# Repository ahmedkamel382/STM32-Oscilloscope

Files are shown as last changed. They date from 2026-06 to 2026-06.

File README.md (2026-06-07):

# ⚡ Digital Storage Oscilloscope (STM32F401)






A high-performance, low-cost Digital Storage Oscilloscope (DSO) engineered from the component level up. Built around the **STM32F401 "Black Pill"**, this project bridges embedded hardware and modern data science by combining a custom Analog Front-End (AFE), deterministic DMA-paced sampling, high-speed USB-CDC telemetry, and an offline Machine Learning waveform classifier.

This project was developed for the **Embedded Systems (ECE5206)** course at the **Arab Academy for Science, Technology and Maritime Transport (AASTMT)**, supervised by **Dr. Amr Fahmy**.

---

## 🚀 Key Features

* **Bipolar Signal Acquisition:** A custom analog conditioning circuit featuring a 1.65V virtual ground allows the single-supply microcontroller ADC to safely read alternating current (AC) waveforms.
* **Active Hardware Protection:** Bipolar Junction Transistor (BJT) clamping arrays (`2N3904` / `2N3906`) actively protect the STM32 silicon from over-voltage and negative voltage spikes.
* **Deterministic Firmware Architecture:** Hardware Timer 2 (`TIM2`) strictly paces ADC conversions, completely bypassing software polling delays.
* **Zero-Loss Data Capture:** Direct Memory Access (DMA) utilizing a Ping-Pong (Half/Full) buffering strategy ensures continuous, uninterrupted sampling while the CPU processes data.
* **High-Speed USB Streaming:** A custom USB-CDC pipeline streams raw binary data (736-byte packets) to the host PC, vastly outperforming standard UART communication.
* **Edge AI Classification:** A fully offline `scikit-learn` Random Forest machine learning model analyzes live mathematical features to automatically classify incoming signals (`Sine`, `Square`, `Triangle`, `Noise`, or `DC`).
* **Zero-Lag Desktop UI:** A multi-threaded Python companion application built with `PyQtGraph` delivers 60-FPS real-time rendering alongside an embedded SQLite database for waveform logging.

---

## 🧰 Technology Stack

### Hardware

* **Microcontroller:** STM32F401CCU6 (`84 MHz Core`, `48 MHz USB`)
* **Local Display:** 240×240 ST7789 TFT Display (`SPI`)
* **Analog Front-End:** Precision `33kΩ / 10kΩ` attenuation networks with `2N3904/06` hardware clamps
* **PCB Design:** Custom single-sided PCB routed in KiCad with dedicated power-rail decoupling

### Software & Firmware

* **Embedded Development:** C/C++, STM32CubeIDE (`HAL` & `LL Drivers`)
* **Desktop Application:** Python 3, PyQtGraph, PyQt5, SQLite3
* **Machine Learning:** `scikit-learn`, `numpy`, `joblib`

> The AI classifier was trained on approximately **6,000 synthesized waveforms**.

---

## 📊 Hardware Specifications & Limits

| Specification | Value | Notes |
|---|---|---|
| **Max Input Voltage** | ~ `-5.44V` to `+8.74V` | Scaled via a `0.1315` attenuation factor |
| **Max Sampling Rate** | ~ `1.56 Msps` | ADCCLK pushed to `42 MHz (DIV2)` |
| **Practical Bandwidth** | ~ `150 kHz` | Based on requiring 10 data points per wave cycle |
| **Hardware Filter** | RC Low-Pass | V1.0 uses a `33pF` capacitor (`102 MHz` cutoff). V2.0 recommends a `4.7nF` capacitor to align the anti-alias cutoff to approximately `720 kHz`. |

---

## ⚙️ Getting Started

### 1. Hardware Setup

1. Assemble the Analog Front-End using the provided KiCad schematics located in:

```text
/Hardware Design
```

2. Ensure proper grounding between the device under test (for example, an ICL8038 signal generator) and the STM32.

3. Connect the STM32 board to your PC using a USB Type-C cable.

---

### 2. Firmware Flashing

1. Open the project using **STM32CubeIDE**.
2. Build the firmware.
3. Flash the firmware to the STM32F401 using an **ST-Link V2** programmer.

---

### 3. Running the Desktop Application

Ensure Python 3 is installed on your system.

Navigate to the desktop application directory and install the dependencies:

```bash
cd dso_pc
pip install -r requirements.txt
```

Launch the desktop UI:

```bash
python dso_app.py
```

> The AI classifier (`dso_model.joblib`) is pre-trained.
>
> If you wish to retrain the model using different parameters, execute:
>
> ```bash
> python train_model.py
> ```
>
> before launching the application.

---

## 👨‍💻 Project Team

### Ahmed Khalid Mohamed

* Lead Analog HW & USB Architect
* 1.65V Virtual Ground & Attenuation Mathematics
* High-Speed USB-CDC Binary Pipeline
* Python Packet Decoding (`dso_protocol.py`)

### Adel Alaa

* Lead Display Driver & AI Engineer
* ST7789 High-Speed Column-Redraw Renderer
* KiCad PCB Routing & Hardware Decoupling
* Live Machine Learning UI Integration

### Bassel Adel

* Lead ADC Firmware & PC UI Engineer
* TIM2-Paced Hardware ADC Triggering
* DMA Ping-Pong Buffering Architecture
* Multithreaded PyQtGraph Desktop UI

### Omar Abdel Nasser Omar

* Lead DSP Firmware & Database Engineer
* Peak-Hold & Interpolation DSP Algorithms
* SQLite Waveform Database Logging
* Random Forest AI Model Training

---

## 📝 License & Academic Disclaimer

This repository contains academic coursework and is provided **as-is** for educational purposes. Do **not** connect this device directly to mains AC voltage or high-voltage circuits without proper industrial isolation and safety equipment.

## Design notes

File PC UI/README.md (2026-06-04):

# AAST DSO — Laptop Companion App

A desktop oscilloscope viewer for the STM32F401 DSO. It reads the device's
existing USB-CDC stream (**no firmware change needed**) and adds a big zoomable
display, cursors, a readings database, and a **real offline AI classifier**.

## Features
- **Live waveform** on a fast PyQtGraph plot. Mouse-drag to pan, scroll to zoom;
  *View → Autoscale* fits the trace.
- **Cursors** (tick the "Cursors" box): two time + two voltage lines; the status
  bar shows Δt and ΔV.
- **0 V offset line** — draggable dashed reference line.
- **Measurements panel** — Vpp / Vmax / Vmin / Vavg / Vrms / Freq / Period,
  straight from the device (so they match the ST7789).
- **Calibration switch** — Config C (current firmware) or Config A (after the
  fix), so the plotted voltage matches the screen.
- **Readings database (SQLite)** — Save a frame, then Overlay one on the live
  trace, Compare two side-by-side, Delete, or Export the list to CSV.
- **AI classifier** — a genuine scikit-learn RandomForest trained offline on
  synthesised sine/square/triangle/noise/DC frames. No internet required.

## Install
```
pip install -r requirements.txt
```

## Run
1. Connect the Black Pill's **own USB-C cable** to the laptop (not the ST-Link).
2. `python dso_app.py`
3. Pick the serial port (press ↻ to rescan) and click **Connect**.

The model `dso_model.joblib` ships ready-trained. To retrain it yourself:
```
python train_model.py
```

## Files
- `dso_app.py` — the GUI application
- `dso_protocol.py` — parses the 736-byte USB packet (96-byte header + 320 samples)
- `dso_features.py` — shared feature extractor (used by app **and** trainer)
- `train_model.py` — synthesises data and trains `dso_model.joblib`
- `dso_model.joblib` — the trained classifier
- `dso_readings.db` — created on first save

## Notes
- If `dso_model.joblib` or scikit-learn is missing, the classifier falls back to
  a crest-factor heuristic so the app still runs.
- A flat trace (<~10 mV motion) is reported as **DC** directly.
- The classifier reaches 100% on sine/square/triangle and ~80% on noise vs DC
  (they overlap at low amplitude) on held-out synthetic data — report it honestly.

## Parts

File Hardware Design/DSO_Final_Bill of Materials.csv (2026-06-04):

Reference | Qty | Value | DNP | Exclude from BOM | Exclude from Board | Footprint | Datasheet
C1 | 1 | 33pF |  |  |  | Capacitor_THT:C_Disc_D5.0mm_W2.5mm_P5.00mm
C2,C5 | 2 | 10uF |  |  |  | Capacitor_THT:CP_Radial_D5.0mm_P2.50mm
C3,C4 | 2 | 100nF |  |  |  | Capacitor_THT:C_Disc_D5.0mm_W2.5mm_P5.00mm
J1 | 1 | Conn_Coaxial |  |  |  | Connector_Coaxial:BNC_TEConnectivity_1478035_Horizontal
J2 | 1 | Conn_01x08 |  |  |  | Connector_PinHeader_2.54mm:PinHeader_1x08_P2.54mm_Vertical
J4,J5 | 2 | Conn_01x20 |  |  |  | Connector_PinHeader_2.54mm:PinHeader_1x20_P2.54mm_Vertical
Q1 | 1 | 2N3906 |  |  |  | Package_TO_SOT_THT:TO-92_Inline_Wide | https://www.onsemi.com/pub/Collateral/2N3906-D.PDF
Q2 | 1 | 2N3904 |  |  |  | Package_TO_SOT_THT:TO-92_Inline_Wide | https://www.onsemi.com/pub/Collateral/2N3903-D.PDF
R1 | 1 | 33k |  |  |  | Resistor_THT:R_Axial_DIN0207_L6.3mm_D2.5mm_P10.16mm_Horizontal
R2,R4,R5 | 3 | 10k |  |  |  | Resistor_THT:R_Axial_DIN0207_L6.3mm_D2.5mm_P10.16mm_Horizontal
R3 | 1 | 47R |  |  |  | Resistor_THT:R_Axial_DIN0207_L6.3mm_D2.5mm_P10.16mm_Horizontal
SW1,SW2,SW3,SW4 | 4 | SW_Push |  |  |  | Button_Switch_THT:SW_PUSH_6mm

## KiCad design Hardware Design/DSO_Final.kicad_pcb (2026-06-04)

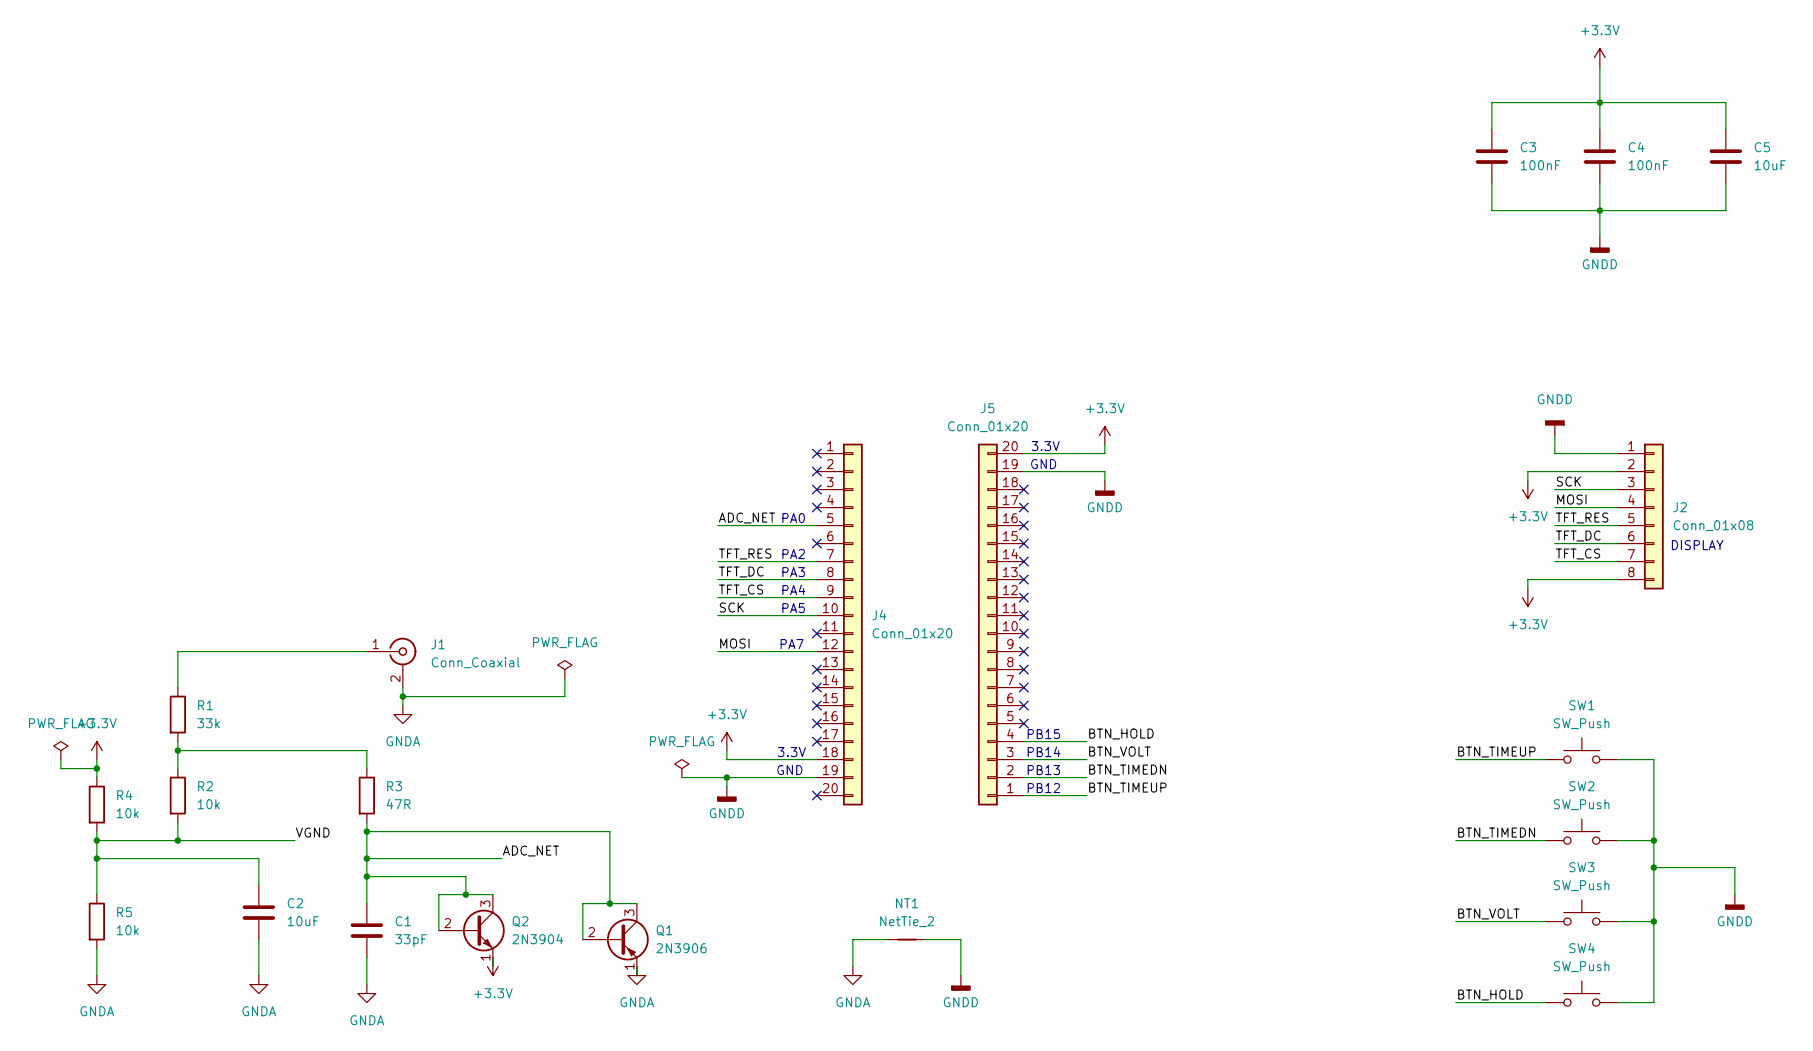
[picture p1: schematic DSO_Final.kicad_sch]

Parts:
C1: 33pF; C_Disc_D5.0mm_W2.5mm_P5.00mm
C2, C5: 10uF; CP_Radial_D5.0mm_P2.50mm
C3, C4: 100nF; C_Disc_D5.0mm_W2.5mm_P5.00mm
J1: Conn_Coaxial; BNC_TEConnectivity_1478035_Horizontal
J2: Conn_01x08; PinHeader_1x08_P2.54mm_Vertical
J4, J5: Conn_01x20; PinHeader_1x20_P2.54mm_Vertical
NT1: NetTie_2; NetTie-2_SMD_Pad0.5mm
Q1: 2N3906; TO-92_Inline_Wide
Q2: 2N3904; TO-92_Inline_Wide
R1: 33k; R_Axial_DIN0207_L6.3mm_D2.5mm_P10.16mm_Horizontal
R2, R4, R5: 10k; R_Axial_DIN0207_L6.3mm_D2.5mm_P10.16mm_Horizontal
R3: 47R; R_Axial_DIN0207_L6.3mm_D2.5mm_P10.16mm_Horizontal
SW1, SW2, SW3, SW4: SW_Push; SW_PUSH_6mm

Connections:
+3.3V: C3.1, C4.1, C5.1, J2.2, J2.8, J4.18, J5.20, Q2.1 (E), R4.1
/ADC_NET: C1.1, J4.5, Q1.2 (B), Q1.3 (C), Q2.2 (B), Q2.3 (C), R3.2
/BTN_HOLD: J5.4, SW4.1
/BTN_TIMEDN: J5.2, SW2.1
/BTN_TIMEUP: J5.1, SW1.1
/BTN_VOLT: J5.3, SW3.1
/MOSI: J2.4, J4.12
/SCK: J2.3, J4.10
/TFT_CS: J2.7, J4.9
/TFT_DC: J2.6, J4.8
/TFT_RES: J2.5, J4.7
/VGND: C2.1, R2.2, R4.2, R5.1
GNDA: C1.2, C2.2, J1.2 (Ext), NT1.1, Q1.1 (E), R5.2
GNDD: C3.2, C4.2, C5.2, J2.1, J4.19, J5.19, NT1.2, SW1.2, SW2.2, SW3.2, SW4.2
unnamed: J1.1 (In), R1.1
unnamed: R1.2, R2.1, R3.1

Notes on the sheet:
3.3V
PA7
PA0
PB14
DISPLAY
GND
PB13
PB12
PA5
PB15
PA4
PA3
PA2

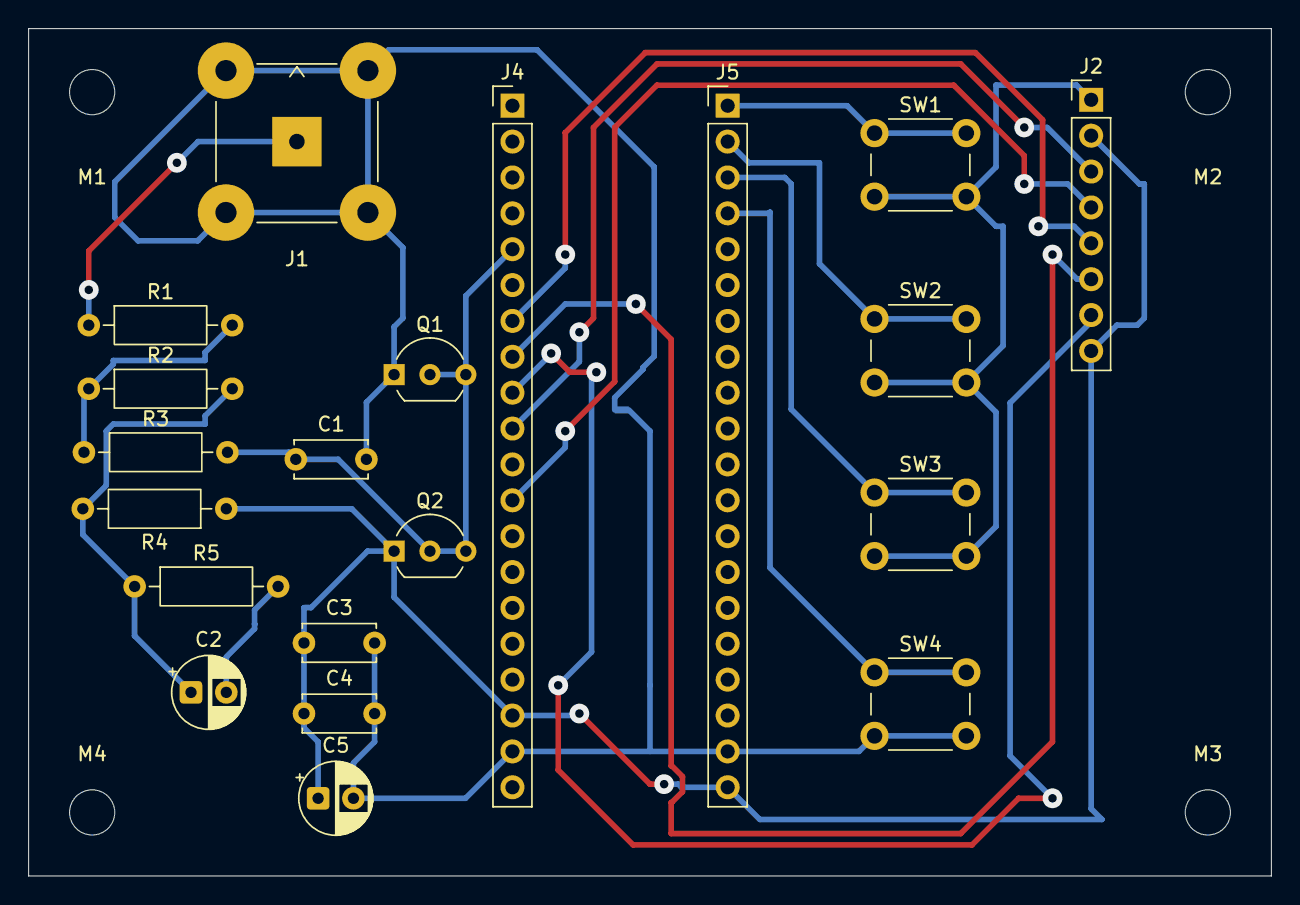
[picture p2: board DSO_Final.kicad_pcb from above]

Board: 2 copper layers, 88.0 x 60.0 mm, 25 parts (1 on the bottom side), 16 nets.

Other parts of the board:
M1, M2, M3, M4: MountingHole_3.2mm_M3

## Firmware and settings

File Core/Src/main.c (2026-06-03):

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
/* Includes ------------------------------------------------------------------*/
#include "main.h"
#include "usb_device.h"

/* USER CODE BEGIN Includes */
#include "st7789.h"
#include "dso.h"
#include "dso_ui.h"   /* NEW: menu / analyzer / signal-memory front-end */
/* USER CODE END Includes */

ADC_HandleTypeDef hadc1;
DMA_HandleTypeDef hdma_adc1;

SPI_HandleTypeDef hspi1;

TIM_HandleTypeDef htim2;

/* USER CODE BEGIN PV */
#include "usbd_cdc_if.h"
static dso_t g_dso;
uint32_t last_blink = 0;
static uint8_t  usb_pkt[96 + SAMPLE_COUNT * 2];  /* 96-byte header + 640 sample bytes */
static uint32_t usb_last_tx = 0;
/* USER CODE END PV */

void SystemClock_Config(void);
static void MX_GPIO_Init(void);
static void MX_DMA_Init(void);
static void MX_ADC1_Init(void);
static void MX_SPI1_Init(void);
static void MX_TIM2_Init(void);
/* USER CODE BEGIN 0 */
/* ============================================================================
 * HAL ADC DMA callbacks  (forward to engine)
 * ============================================================================
 */
void HAL_ADC_ConvHalfCpltCallback(ADC_HandleTypeDef *hadc) {
    if (hadc->Instance == ADC1) DSO_OnDMA_HalfComplete(&g_dso);
}

void HAL_ADC_ConvCpltCallback(ADC_HandleTypeDef *hadc) {
    if (hadc->Instance == ADC1) DSO_OnDMA_FullComplete(&g_dso);
}
/* USER CODE END 0 */

/**
  * @brief  The application entry point.
  * @retval int
  */
int main(void)
{

  /* MCU Configuration--------------------------------------------------------*/

  /* Reset of all peripherals, Initializes the Flash interface and the Systick. */
  HAL_Init();

  /* Configure the system clock */
  SystemClock_Config();

  /* Initialize all configured peripherals */
  MX_GPIO_Init();
  MX_DMA_Init();
  MX_ADC1_Init();
  MX_SPI1_Init();
  MX_TIM2_Init();
  MX_USB_DEVICE_Init();
  /* USER CODE BEGIN 2 */
  /* Status LED on -- blinks once we're rendering */
  HAL_GPIO_WritePin(LED_GPIO_Port, LED_Pin, GPIO_PIN_RESET);

  /* TFT Initialization */
  ST7789_Init(&hspi1);
  ST7789_FillScreen(COLOR_BLACK);
  ST7789_DrawString(40, 70, "AAST DSO booting...", COLOR_YELLOW, COLOR_BLACK, 2);

  /* Give the host ~1.5 s to enumerate the USB CDC port before we start
   * spamming packets at 20 Hz.  Otherwise the first few frames are lost. */
  HAL_Delay(1500);

  /* DSO engine Initialization */
  DSO_Init(&g_dso, &hadc1, &htim2, &hspi1);
  DSO_Start(&g_dso);
  /* NEW: bring up the button-navigated menu first.  DSO_UI_Init draws the
   * menu screen itself, so the old boot-time DSO_RedrawStaticUI() call is no
   * longer needed here -- the UI module redraws the scope when you enter it. */
  DSO_UI_Init(&g_dso);
  /* USER CODE END 2 */

  /* Infinite loop */
  /* USER CODE BEGIN WHILE */
    while (1)
    {
  	  /* AGGRESSIVE CRASH FIX: If the ADC panics, fully restart the DMA */
  	   if (__HAL_ADC_GET_FLAG(&hadc1, ADC_FLAG_OVR)) {
  		 HAL_ADC_Stop_DMA(&hadc1);
  		 HAL_ADC_Stop(&hadc1);

  		 __HAL_ADC_CLEAR_FLAG(&hadc1, ADC_FLAG_OVR);

  		 HAL_ADC_Start_DMA(&hadc1, (uint32_t *)g_dso.buf_a, SAMPLE_COUNT);
  	        }

        /* NEW: single entry point that runs the menu / analysis / memory
         * state machine.  In Live Scope mode it calls the original
         * DSO_PollButtons() + DSO_ProcessFrame() internally, unchanged. */
        DSO_UI_Task(&g_dso);

        uint32_t now = HAL_GetTick();
        if (now - last_blink > 500) {
            HAL_GPIO_TogglePin(LED_GPIO_Port, LED_Pin);
            last_blink = now;
        }

        /* USB Transmission Block (~20 packets / second).
         * Packet layout (fixed total = 96 header bytes + 640 sample bytes):
         *   bytes [0..95]   : ASCII "DSO,vmax,vmin,vpp,vavg,vrms,freq,period\n"
         *                     padded with spaces to exactly 96 bytes.
         *   bytes [96..735] : 320 raw ADC samples, little-endian uint16.
         * Total = 736 bytes per packet -- always identical so the Python
         * viewer can sync on the "DSO," header and read a fixed run.
         */
        if (now - usb_last_tx >= 50) {
            usb_last_tx = now;
            int n = snprintf((char *)usb_pkt, 96,
                "DSO,%ld,%ld,%ld,%ld,%ld,%lu,%lu\n",
                (long)g_dso.meas.vmax_mv,  (long)g_dso.meas.vmin_mv,
                (long)g_dso.meas.vpp_mv,   (long)g_dso.meas.vavg_mv,
                (long)g_dso.meas.vrms_mv,
                (unsigned long)g_dso.meas.freq_hz,
                (unsigned long)g_dso.meas.period_us);
            /* Pad the header region to exactly 96 bytes with spaces. */
            if (n < 0) n = 0;
            if (n > 95) n = 95;
            for (int k = n; k < 95; ++k) usb_pkt[k] = ' ';
            usb_pkt[95] = '\n';

            /* Append the 320 raw ADC samples (640 bytes). */
            const uint16_t *buf = (const uint16_t *)g_dso.buf_b;
            memcpy(&usb_pkt[96], buf, SAMPLE_COUNT * 2);

            /* Only send if USB driver is idle -- prevents overrun freezes. */
            (void)CDC_Transmit_FS(usb_pkt, 96 + SAMPLE_COUNT * 2);
        }
    /* USER CODE END WHILE */

    /* USER CODE BEGIN 3 */
    }
  /* USER CODE END 3 */
}

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


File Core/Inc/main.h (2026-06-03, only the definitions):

#define LED_Pin GPIO_PIN_13
#define LED_GPIO_Port GPIOC
#define TFT_RST_Pin GPIO_PIN_2
#define TFT_RST_GPIO_Port GPIOA
#define TFT_DC_Pin GPIO_PIN_3
#define TFT_DC_GPIO_Port GPIOA
#define TFT_CS_Pin GPIO_PIN_4
#define TFT_CS_GPIO_Port GPIOA
#define BTN_TIMEUP_Pin GPIO_PIN_12
#define BTN_TIMEUP_GPIO_Port GPIOB
#define BTN_TIMEDN_Pin GPIO_PIN_13
#define BTN_TIMEDN_GPIO_Port GPIOB
#define BTN_VOLT_Pin GPIO_PIN_14
#define BTN_VOLT_GPIO_Port GPIOB
#define BTN_HOLD_Pin GPIO_PIN_15
#define BTN_HOLD_GPIO_Port GPIOB

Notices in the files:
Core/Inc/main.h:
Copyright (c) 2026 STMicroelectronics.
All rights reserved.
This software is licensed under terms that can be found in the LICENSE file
